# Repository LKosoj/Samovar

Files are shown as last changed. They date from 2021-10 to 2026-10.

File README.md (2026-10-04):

# Проект Самовар

[English version](README_EN.md)

## Описание
Автоматизированная система управления самогонным аппаратом, пивоварней и сыроварней на базе ESP32
(версия прошивки 7.00). Устройство измеряет температуры (пар, царга, куб, вода на выходе, ТСА) и
давление, управляет нагревом через регулятор мощности, реле, клапанами, насосом воды, шаговым
двигателем с перистальтическим насосом для отбора и сервоприводом для раздельного отбора по
ёмкостям. Процесс описывается программой из строк, которые выполняются последовательно, а логику
можно расширять скриптами на Lua. Управлять и наблюдать можно с локального дисплея, из встроенного
веб-интерфейса, из мобильных приложений для Android и iOS и со страницы на сайте samovar-tool.ru.
При выходе параметров за допустимые пределы устройство останавливает процесс и присылает тревогу.

## Режимы работы
- **Ректификация** — отбор голов, тела и хвостов по программе, детектор проскока примесей:
  анализирует тренд температуры с поправкой на давление, порог подбирает сам по шуму колонны,
  при росте температуры по желанию снижает скорость отбора, при критическом росте ставит отбор
  на паузу и сам возобновляет; на головах только наблюдает, а причину ожидания (грейс-период,
  стабилизация пара, набор истории) показывает в интерфейсе. Раздельный отбор по ёмкостям
  сервоприводом.
- **Дистилляция** — по температуре в кубе или по изменению спиртуозности в кубе или в паре, с
  прогнозом времени до конца строки и всего процесса.
- **БК (бражная колонна)** — управление водой охлаждения по уставке температуры пара
  (автоматически или вручную), подтверждение кипения по датчикам.
- **НБК (непрерывная бражная колонна)** — прогрев, настройка, оптимизация и работа; подача
  браги регулируется автоматически, найденные параметры можно принять как оптимальные.
- **Пивоварение** — засыпь солода, температурные паузы, кипячение, охлаждение, брожение, варочные
  порядки, управление мешалкой и насосом воды, ручная пауза.
- **Сувид** — термостат: держит заданную температуру по датчику куба в течение заданного
  времени выдержки (0 — без ограничения); уставка и время задаются в настройках.
- **Сыроварение** — нагрев, выдержки, охлаждение, контроль кислотности по датчику pH, мешалка,
  клапан слива; свои типы строк программы (нагрев, выдержка, охлаждение, перемешивание,
  дозирование, ожидание pH, флокуляция, ручное действие, слив, Lua).
- **Lua** — режим, в котором весь процесс ведёт пользовательский скрипт.

## Основные возможности
- Программа процесса для ректификации, дистилляции, БК, НБК, пива и сыра: набор строк,
  задаётся в веб-интерфейсе, выполняется последовательно. Подробнее в документации и на форуме.
- Плавное управление мощностью через внешние регуляторы (в том числе Kvic новой версии, РМВК,
  СЭМ) с автокоррекцией температуры кипения по атмосферному давлению.
- Точное управление отбором: скорость в литрах в час поддерживается автоматически.
- Плата расширения I2CStepper по шине I2C: мешалка и дозирующий насос на шаговых двигателях —
  прокачка, наполнение заданного объёма, калибровка «шагов на миллилитр», реле, внешний датчик.
  Управляется из веб-интерфейса, программы, Lua, мобильных приложений и сайта.
- Встроенный интерпретатор Lua для расширения логики: доступ к датчикам, нагреву, насосам,
  мешалке, реле.
- Безопасность: контроль температур, давления, воды, ошибок регулятора и датчиков; аварийная
  кнопка; при аварии процесс останавливается, а сообщение уходит на дисплей, в веб-интерфейс,
  в приложения и на сайт.
- Снимки состояния: после аварийной перезагрузки прошивка восстанавливает программу и, если
  процесс перезапущен в течение 30 минут, продолжает ту же сессию лога.
- Веб-интерфейс с графиками в реальном времени, схемой процесса и файловым менеджером; локальный
  LCD-дисплей с энкодером.
- Лог процесса и сообщения сохраняются в облаке (сервер samovar-tool.ru) и доступны на сайте и в
  приложениях; графики строятся по истории всей сессии.
- Мобильные приложения Android и iOS и страница управления на сайте (см. разделы ниже), push-
  уведомления о тревогах.
- Конфигуратор для Windows, macOS и Linux: сборка, прошивка по USB или Wi-Fi, редактор файлов
  устройства, отчёт о конфигурации.
- Поддержка ESP32 (DEVKIT, LILYGO) и ESP32-S3.

## Требования
### Аппаратные
- ESP32 (DEVKIT, LILYGO) или ESP32-S3
- Датчики температуры DS18B20 (5 шт)
- Датчик давления (MPX5010D, XGZP6897D или датчик 1-Wire), датчик атмосферного давления
  (BME680, BME280, BMP280 или BMP180)
- Регулятор мощности (Kvic, РМВК, СЭМ или аналог)
- LCD дисплей
- Энкодер с кнопкой
- Насос для подачи воды
- Шаговый двигатель
- Перистальтический насос
- Клапаны
- Сервопривод
- Блок питания
- По желанию: плата I2CStepper с мешалкой и дозирующим насосом, внешний АЦП ADS1115 и
  датчик pH PH-4502C для сыроварения, датчик протока воды, аварийная кнопка

Для режима «Сыр» используются общие контакты:

- `#define USE_ADS1115 0x48` автоматически переводит датчик pH на вход AIN0 ADS1115
  по адресу `0x48`. Отдельной настройки канала нет. `LUA_PIN` для pH не используется.
  Если ADS1115 не найден, запуск сыроварения и калибровка pH блокируются, но остальные
  режимы продолжают работать.
- Без `USE_ADS1115` входом PH-4502C служит `LUA_PIN`;
  оператор подключает к нему либо PH-4502C для сыра, либо MPX5010DP для других режимов,
  но не оба датчика одновременно.
- Реле №4 — клапан слива; оператор подключает к нему либо клапан для сыра,
  либо разгонный ТЭН для других режимов, но не оба устройства одновременно.

Это назначение действует только в режиме «Сыр». В остальных режимах Lua,
MPX5010DP и разгонный ТЭН работают как обычно.

Схема подключения
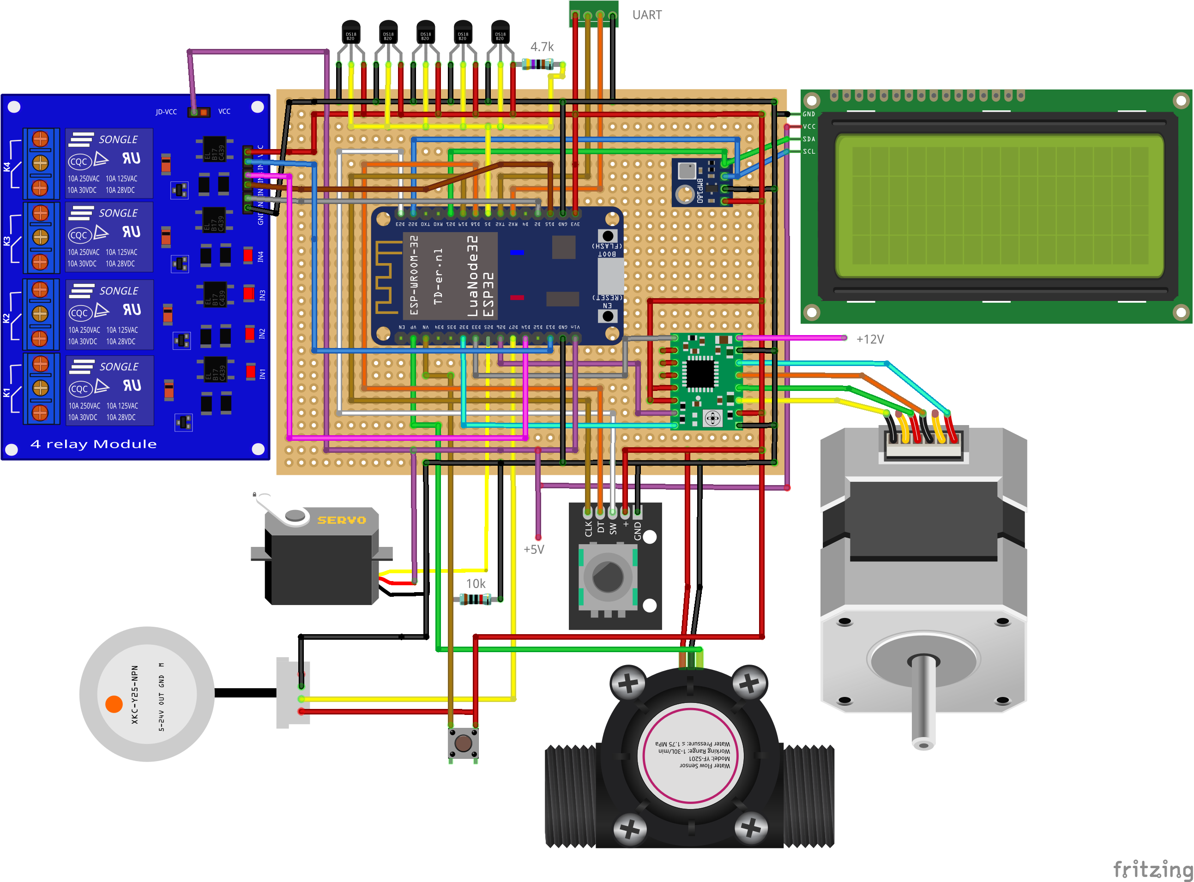
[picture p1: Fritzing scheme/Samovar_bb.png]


### Ограничения выводов ESP32
- GPIO34–39 — только входы, внутренних подтяжек нет: для аварийной кнопки (GPIO35 на DEVKIT), энкодера LILYGO (GPIO35/39/36) и датчика протока (GPIO36 на DEVKIT) обязателен внешний резистор 10 кОм к 3.3 В; без него — ложные срабатывания и уход в аварию сразу после включения.
- GPIO36/39 — ложные импульсы при работе АЦП и Wi-Fi: провода к датчику протока вести отдельно от силовых кабелей ТЭНа.
- GPIO15 и другие strapping-выводы аппаратно подтянуты при сбросе: реле на таком выводе (RELE_CHANNEL2, мешалка) кратковременно включается при каждой загрузке — использовать реле с активным низким уровнем либо перенести на обычный вывод; полярность задаётся полями rele1…rele4 в setup.htm.
- На ESP32-S3 кнопка меню (GPIO47) требует внешней подтяжки.
- Шина I2C (дисплей, плата расширения шагового двигателя, дозирующий насос): подтяжки 4.7–10 кОм; длина проводов и частота шины — причина срывов отрисовки, из-за которых в прошивке есть периодическая переинициализация дисплея.

### Программные
- Windows 10/11 x64: достаточно запустить `flash_windows.bat`. Он проверит или
  установит Python с Tkinter и PlatformIO, затем откроет конфигуратор Samovar.
- macOS и Linux: запустите `./flash_macos_linux.sh`. Он проверит или установит
  Python с Tkinter и PlatformIO, затем откроет тот же конфигуратор.
- Для ручной сборки на любой поддерживаемой системе нужен PlatformIO Core. Компилятор
  ESP32, платформу и зависимости проекта PlatformIO устанавливает автоматически по
  `platformio.ini`; отдельно собирать список библиотек не требуется.

## Установка

### Windows: конфигуратор

1. Скачайте или клонируйте репозиторий и запустите `flash_windows.bat` из его корня.
2. В открывшемся окне выберите плату и задайте параметры. Локальные настройки,
   включая исходные реквизиты Wi-Fi, сохраняются в `user_config_override.h`.
3. Нажмите «Прошить»: PlatformIO скомпилирует прошивку и загрузит её в ESP32.
4. При первой установке отдельно нажмите «Загрузить LittleFS», чтобы записать
   веб-интерфейс. Эта операция требует подтверждения, поскольку заменяет файлы на
   устройстве.
5. Последующие обновления можно ставить без кабеля. Нажмите «Обновить» рядом с
   полем «Порт или адрес»: кроме COM-портов в список попадают устройства Samovar,
   найденные в сети (mDNS, поиск занимает около трёх секунд), а также адрес,
   который устройство сообщило после кнопки «Получить IP» в мониторе порта. Адрес
   можно и ввести вручную (`192.168.1.37` или `samovar.local`). Выберите
   устройство в сети вместо COM-порта и нажмите те же «Прошить» или «Загрузить
   LittleFS» — PlatformIO сам передаст образ по Wi-Fi. Условия: прошивка на
   устройстве собрана с включённым «Разрешить обновление по Wi-Fi» (раздел
   «Сеть»), компьютер и Samovar в одной сети, брандмауэр разрешает `python.exe`
   входящие подключения — при передаче образа устройство само подключается к
   компьютеру. Полная очистка флеша, монитор порта и перезагрузка через esptool
   работают только по USB.

Кнопка «Редактор файлов» открывает файлы устройства прямо в конфигураторе:
с номерами строк, подсветкой Lua, JS, CSS, HTML и JSON, подсветкой парной
скобки и быстрой проверкой (баланс скобок и блоков `function … end`, незакрытые
строки и комментарии, корректность JSON). Ошибка показывается в строке состояния
с номером строки. Для подсказок при вводе и полной проверки синтаксиса кнопка
«Веб-редактор (/edit)» открывает тот же файл в редакторе Ace на устройстве; для сжатых файлов (.gz) кнопка недоступна, их редактируют здесь, конфигуратор распаковывает и запаковывает их сам.

Во всех полях и в журнале работает контекстное меню по правой кнопке мыши
(вырезать, копировать, вставить, выделить всё), а сочетания Ctrl+C, Ctrl+V,
Ctrl+X, Ctrl+A действуют и в русской раскладке.

`flash_windows.bat` только подготавливает инструменты и запускает
`tools/samovar_configurator.py`; компиляцию и загрузку выполняет PlatformIO.
Конфигуратор изменяет пользовательские параметры, но не заменяет компилятор:
прошивку всегда собирает PlatformIO отдельным шагом.

### Arduino IDE

Arduino IDE — отдельный поддерживаемый способ сборки и загрузки. Откройте
корневой `Samovar.ino`, выберите свою ESP32-плату и порт, затем соберите и загрузите
прошивку. Для первой установки отдельно загрузите LittleFS с подготовленным каталогом
`data/`; конфигуратор и PlatformIO для этого способа не обязательны.

### macOS и Linux: конфигуратор

1. Скачайте или клонируйте репозиторий. В macOS рекомендуется разместить папку проекта
   непосредственно в домашней папке, а не в защищённой папке `Downloads` («Загрузки»).
2. Откройте Terminal в папке проекта и выполните:

   ```sh
   chmod +x flash_macos_linux.sh
   ./flash_macos_linux.sh
   ```

3. В открывшемся окне настройте и прошейте устройство так же, как в Windows.

Если macOS выводит `getcwd: cannot access parent directories: Operation not permitted`
или не разрешает открыть `flash_macos_linux.sh`, оболочка не имеет доступа к текущей
папке и скрипт ещё не начал выполняться. Перенесите папку проекта через Finder из
`Downloads` в домашнюю папку и запустите его оттуда. Другой вариант: откройте
«Системные настройки» → «Конфиденциальность и безопасность» → «Файлы и папки»,
разрешите Terminal доступ к папке «Загрузки» и полностью перезапустите Terminal.

В macOS для автоматической установки Python и Tkinter требуется Homebrew. В Linux
поддерживаются `apt`, `dnf` и `pacman`; установка системных пакетов может запросить
пароль `sudo` (запуск команды с правами администратора).

### Ручная сборка PlatformIO

1. Установите PlatformIO Core и клонируйте репозиторий.
2. Задайте пользовательские параметры в `user_config_override.h`, взяв за основу
   `user_config_override.example.h`.
3. Соберите и загрузите нужное окружение: `pio run -e Samovar -t upload` для ESP32
   DEVKIT/LILYGO (для LILYGO добавьте в `user_config_override.h` строку `#define BOARD LILYGO`)
   или `pio run -e Samovar_s3 -t upload` для ESP32-S3.
4. Для первой установки веб-интерфейса выполните для того же окружения
   `pio run -e <окружение> -t uploadfs`.

## Языки

Язык прошивки и веб-интерфейса выбирается при прошивке; переключать его на работающем
устройстве нельзя. Доступны русский, английский (`en`), немецкий (`de`), французский
(`fr`), испанский (`es`) и китайский (`zh`). Каталог рецептов пива и сыра с сайта
открывается на языке устройства.

- **Конфигуратор.** В разделе «Основные» выберите «Язык прошивки и веб-интерфейса», затем
  «Прошить» и «Загрузить LittleFS»: конфигуратор сам соберёт образ веб-интерфейса на
  выбранном языке. Язык окна самого конфигуратора выбирается внизу окна и применяется
  после перезапуска.
- **Вручную.** Добавьте в `user_config_override.h` строку `#define SAMOVAR_LANG en`.
  Образ веб-интерфейса на английском собирается командой
  `python3 tools/build_web_assets.py --image en --out <каталог вне проекта>` (каталог не должен
  существовать или должен быть пустым); этот каталог
  загружается в LittleFS вместо `data/` (для PlatformIO — через переменную окружения
  `PLATFORMIO_DATA_DIR=<каталог>`).
- **Обновление веб-интерфейса по сети.** Устройство само скачивает с сервера файлы своего
  языка (`index.en.htm.gz` и т. п.) и сохраняет их под обычными именами. Ваши `.lua` и
  `program_*.txt` при этом не перезаписываются: после смены языка они остаются прежними,
  пока вы не удалите их или не загрузите LittleFS заново.

Русский текст остаётся в коде: строки прошивки записаны как `TR(КЛЮЧ, "русский текст")`,
перевод лежит в `lang_<код>.h`. Если для какой-то строки нет перевода, сборка падает с
ошибкой — подстановки русского текста вместо перевода нет. Веб-интерфейс переводится при
сборке `tools/build_web_assets.py` по словарю `i18n/web/<код>.json`, конфигуратор — по
`i18n/configurator/<код>.json`.

Чтобы добавить язык, положите в корень `lang_<код>.h` (по образцу `lang_en.h`), а также
`i18n/web/<код>.json` и `i18n/configurator/<код>.json`. Конфигуратор найдёт новый язык
сам. Полноту переводов проверяют `tools/smoke_i18n_firmware.py`, `tools/smoke_i18n_web.py`
и `tools/smoke_i18n_configurator.py`. После правки только `lang_<код>.h` выполните чистую
сборку (`pio run -e <окружение> -t clean`): PlatformIO не видит этот файл в зависимостях,
потому что имя подключаемого файла вычисляется макросом.

## Структура проекта
- `Samovar.ino` - основной файл проекта
- `Samovar.h` - основные определения
- `logic.h` - логика работы
- `WebServer.ino` - веб-сервер
- `Blynk.ino` - связь с сервером samovar-tool.ru (данные, команды, лог процесса)
- `SamovarMqtt.h` - необязательная отправка показаний в MQTT
- `I2CStepper.h`, `i2c_stepper_params.h` - плата расширения: мешалка и дозирующий насос по I2C
- `impurity_detector.h` - детектор проскока примесей
- `FS.ino` - файловая система, локальный лог и снимки состояния для восстановления после перезагрузки
- `crash_handler.h` - необязательный отчёт о сбое (`USE_CRASH_HANDLER`)
- `tools/samovar_configurator.py` - конфигуратор (запускается из `flash_windows.bat` и `flash_macos_linux.sh`)
- `beer.h` - режим пивоварения
- `cheese.h` - режим сыроварения
- `distiller.h` - режим дистилляции
- `BK.h` - режим бражной колонны
- `nbk.h` - режим непрерывной бражной колонны
- `lua.h` - интерпретатор Lua

### Веб-интерфейс

Интерфейс в «медной» палитре со светлой и тёмной темой (по настройке системы или
переключателем): схема процесса с живыми показаниями, текущая строка
программы, графики, страницы режимов, настройки, редактор программ и файлов.

Рабочие страницы загружаются как статические gzip-файлы и до первого опроса получают
начальные данные одним запросом `/ui-bootstrap`. Единственное исключение — `setup.htm`:
она остаётся несжатой шаблонной страницей.

### Редактор файлов устройства

Операции редактора `/edit`, меняющие файловую систему (`DELETE`, создание через
`PUT` и каждый чанк загрузки), пытаются без ожидания получить общий доступ к
файлам. Если журнал в этот момент занят, сервер отвечает `503 BUSY`; если доступ
свободен, операция разрешена и во время процесса. Просмотр и скачивание файлов
остаются доступны всегда.

### Связь с сервером, лог процесса и сессии

Связь устройства с сайтом и приложениями идёт через сервер samovar-tool.ru по протоколу Blynk
(TCP, порт 8080). По нему уходят живые показания и команды для приложений и сайта, а также лог
процесса, старт сессии и сообщения (виртуальные пины V34, V35 и V26): сервер сам записывает их в
базу, откуда их читают страница логов на сайте и графики в приложениях. Периоды фиксированы:
строка лога уходит на сервер раз в `LOG_PERIOD_S = 4` секунды, в локальный файл `data.csv`
пишется раз в `FILE_LOG_PERIOD_S = 16` секунд; настроек в веб-интерфейсе для этого нет. В простое
(нет активного процесса) показания всё равно уходят раз в 5 секунд, чтобы
приложения видели температуры и без запущенного процесса.

По желанию конфигуратор включает отдельную отправку сокращённой строки показаний в произвольный
MQTT-брокер. Сервер, порт, пользователь, пароль и топик хранятся только в локальном
`user_config_override.h`; веб-интерфейс устройства их не хранит. MQTT работает без TLS, отправляет
сообщения с QoS 1 и сохраняет последнее значение в брокере (`retain`). В процессе период равен
4 секундам, в простое — 5 секундам.

Если процесс прервался аварийной перезагрузкой и его же программу запускают заново в течение
30 минут, прошивка не открывает новую сессию, а продолжает прежнюю — сервер дописывает
существующую запись лога, а не создаёт новую.

## Мобильные приложения

Приложения для Android и iOS устроены одинаково и работают через сервер samovar-tool.ru:
при первом запуске регистрируют или используют существующий аккаунт (email и пароль),
в настройках задаётся токен устройства — тот же, что в прошивке, — или подключаются устройства,
добавленные на сайте.

Четыре основные вкладки и меню «Ещё»:
- **Основная** — состояние связи, схема процесса с живыми температурами, ключевые показания,
  текущая строка программы с прогрессом, кнопки нагрева, «Далее», паузы и сброса процесса,
  блок режима (спиртуозность, детектор примесей, прогнозы, подача браги, pH и т. д.).
- **Программа** — все строки программы с расшифровкой полей, выполняемая строка подсвечена.
- **Управление** — напряжение, скорость отбора, фиксация температуры тела, мешалка и насос
  I2CStepper (настройки, запуск, калибровка, реле), выполнение строк Lua с ответом устройства,
  системная информация, сообщения за сеанс.
- **Графики** — история текущей сессии из базы сервера плюс живые точки, группы серий и
  интервалы от 1 минуты до всей сессии.
- **Ещё** — разделы «Сыровар» и «Пивовар» (журналы, рецепты, склад, калькуляторы), «Винокур»
  (журналы, калькуляторы) и «Настройки» (токен или устройства сайта, аккаунт, тема оформления).

Данные обновляются раз в 3 секунды, пока приложение на экране. Тревоги приходят push-уведомлением
с громким сигналом и показываются поверх экрана блокировки. На планшете экраны двухколоночные.

## Управление через сайт samovar-tool.ru

На сайте есть страница https://www.samovar-tool.ru/control/ — экраны Основная, Программа,
Управление, Графики и Сообщения, как в мобильных приложениях, без установки чего-либо на телефон
или компьютер. Условия:

- нужно войти на сайт;
- к аккаунту должно быть добавлено устройство (токен тот же, что в прошивке и в приложениях) —
  на странице «Пользователь → Устройства». Если устройств несколько, нужное выбирается на странице
  управления. Без устройства страница сообщает, что его сначала нужно добавить.

Сайт обращается к серверу от имени пользователя сам, токен в браузер не передаётся.
Команды отправляются только когда устройство в сети, при устаревших данных кнопки блокируются.
Страница логов https://www.samovar-tool.ru/logi/ (список сессий, графики, сообщения, выгрузка
CSV) дополняет страницу управления.

## Документация
Полная документация доступна на сайте: https://www.samovar-tool.ru/

[Техническая документация](/doc/tutorial.md)

## Поддержка
Проект некоммерческий. Обсуждение и поддержка на форуме:
https://forum.homedistiller.ru/index.php?topic=367128.0

## Демонстрация
Примеры работы системы: https://www.samovar-tool.ru/2021/03/21/o-rabote-samovara/

## Сравнение с другими проектами

### Ректификация/дистилляция
Давайте сравним функционал проекта "Самовар" с коммерческими решениями для ректификации и дистилляции, разделив их на три категории:

1.  **Базовые цифровые контроллеры** (например, популярные PID-регуляторы в коробке, контроллеры от Still Spirits и т.п.).
2.  **Продвинутые хоббийные контроллеры** (например, системы от HomeDistiller, кастомные сборки от известных производителей оборудования).
3.  **Промышленные/лабораторные ПЛК-системы** (Programmable Logic Controller — программируемые логические контроллеры).

---

### Сравнительный анализ функционала для дистилляции/ректификации

| Функциональный блок | Проект "Самовар" (DIY) | Базовый контроллер | Продвинутый хобби-контроллер | Промышленный ПЛК |
| :--- | :--- | :--- | :--- | :--- |
| **1. Основная логика управления** | **Динамическое управление процессом.** Логика зависит от стадии, температуры, давления, времени и **событий**. | **Статическое поддержание параметра.** Обычно это термостат: держит заданную температуру или мощность. | **Пошаговое программирование.** Выполнение рецепта вида: "греть до 80°С -> держать 20 мин -> греть до 90°С". | **Полностью программируемая логика.** Реализуется любая, даже самая сложная взаимосвязь между параметрами. |
| **2. Управление мощностью** | **Плавное, точное.** ПИД-регулирование мощности через внешние регуляторы (симисторы, SSR). | **Дискретное (Вкл/Выкл).** Простое реле, приводящее к инерционным скачкам температуры. | **Плавное.** Обычно ПИД-управление через ФИМ (фазо-импульсная модуляция) для SSR. | **Плавное, прецизионное.** Управление с обратной связью по мощности. |
| **3. Управление отбором продукта** | **Ключевая функция.** **Высокоточное управление шаговым двигателем насоса** или сервоприводом клапана. Скорость отбора задается в л/ч и автоматически поддерживается. | **Отсутствует.** Управляется вручную оператором. | **Обычно отсутствует или опционально.** Может управлять простым клапаном (открыт/закрыт), но редко — скоростью отбора. | **Полный контроль.** Управление любыми типами клапанов и насосов с контролем потока. |
| **4. Адаптивность к процессу** | **Очень высокая.** **Автокоррекция температуры кипения по давлению.** **Автоматическое снижение скорости отбора** при "подходе хвостов". **Полная кастомизация логики через Lua.** | **Нулевая.** Не реагирует ни на что, кроме отклонения от заданной температуры. | **Низкая.** Может переключить шаг рецепта по событию (например, по достижению температуры), но не может динамически изменять параметры текущего шага. | **Абсолютная.** Логика пишется под конкретную установку и процесс. |
| **5. Интерфейс и мониторинг** | **Современный.** Веб-интерфейс с графиками в реальном времени, удаленный доступ, локальный LCD. | **Примитивный.** Цифровой индикатор и несколько кнопок. | **Функциональный, но утилитарный.** Часто это текстовый LCD, опционально — вывод данных на ПК через RS-485/USB. | **Промышленный.** SCADA-системы с полной визуализацией процесса, архивацией, отчетами. |
| **6. Безопасность** | **Многоуровневая, настраиваемая.** Контроль температуры, давления, воды, ошибок питания. Логика аварии задается пользователем. | **Базовая.** Обычно только защита от перегрева. | **Хорошая.** Контроль нескольких датчиков, сторожевые таймеры. | **Максимальная.** Дублирование систем, сертифицированные компоненты, аппаратные защиты. |
| **7. Интеграции (IoT)** | **Встроенные.** Облачный лог, мобильные приложения Android/iOS, управление через сайт samovar-tool.ru. | **Отсутствуют.** | **Редко.** Обычно это проприетарные протоколы или ModBus для связи с ПК. | **Стандарт.** OPC-UA, ModBus, Profinet и др. промышленные протоколы. |
| **8. Примерная стоимость** | **Низкая** (~$50-100 за электронику). | **Низкая** (~$50-150). | **Средняя/Высокая** (~$300-800). | **Очень высокая** (тысячи $). |

---

### Позиционирование "Самовара" относительно других проектов для дистилляции

1.  **"Самовар" на голову превосходит базовые контроллеры.** Он не просто заменяет их, а предлагает совершенно иной уровень автоматизации. Там, где базовый контроллер — это "умная розетка", "Самовар" — это "мозг" установки.

2.  **"Самовар" является прямым и очень сильным конкурентом продвинутым хобби-контроллерам.** Он не только не уступает им в основных функциях (ПИД-регулирование мощности, пошаговые программы), но и **превосходит их в двух критически важных для ректификации областях:**
    *   **Интегрированное управление отбором:** У коммерческих систем управление отбором — это, как правило, отдельное, дорогое устройство. "Самовар" делает это своей основной функцией.
    *   **Гибкость логики:** Ни один коммерческий хобби-контроллер не предлагает программирование логики на уровне Lua. Эта возможность переносит "Самовар" в полупрофессиональную лигу, позволяя реализовать алгоритмы, доступные ранее только на промышленных ПЛК.

3.  **"Самовар" заимствует концепции у промышленных ПЛК-систем.** Идея полностью программируемой логики, реагирующей на множество асинхронных событий, — это основа ПЛК. "Самовар" демократизирует этот подход, делая его доступным для хоббиста на дешевой аппаратной базе. Разумеется, он уступает в надежности, помехозащищенности и не имеет промышленных сертификатов, но с точки зрения **функциональной логики** — он стремится именно в эту высшую лигу.

**Итоговый вывод:**

Проект "Самовар" — это не просто DIY-поделка. В контексте оборудования для дистилляции/ректификации он представляет собой **систему, которая по своему функционалу оставляет далеко позади остальные DIY решения и напрямую конкурирует с дорогими продвинутыми контроллерами, превосходя их в гибкости и возможностях кастомизации.**

Его главный компромисс — это не функционал, а **"удобство против гибкости"**. Покупая коммерческий прибор, вы получаете гарантию, поддержку и готовое к работе устройство. Выбирая "Самовар", вы получаете практически безграничные возможности для автоматизации в обмен на необходимость самостоятельно собирать, настраивать и обслуживать систему.

### Сравнительный анализ функционала для режима пивоварения

Ниже приведен сравнительный анализ функционала проекта "Самовар" с другими популярными open-source/DIY проектами в области автоматизации пивоварения.

Для сравнения возьмем несколько известных проектов, представляющих разные подходы:
1.  **BrewPi / BrewPiLess:** Исторически один из самых известных проектов для **контроля ферментации** пива.
2.  **CraftBeerPi (v3/v4):** Очень популярный и модульный контроллер для **пивоварения** (затирание, кипячение), работающий на Raspberry Pi.
3.  **ArdBir / ESPurno:** Более простые контроллеры на Arduino/ESP, ориентированные в основном на процесс пивоварения.

---

### Сравнительный анализ по ключевым параметрам

| Функциональный блок | Проект "Самовар" | BrewPi / BrewPiLess | CraftBeerPi 4 | Типичные DIY-проекты (ArdBir и др.) |
| :--- | :--- | :--- | :--- | :--- |
| **1. Целевое назначение** | **Универсальный.** Дистилляция, ректификация, пивоварение, НБК. | **Специализированный.** В основном, точный контроль температуры ферментации. | **Специализированный.** Полный цикл пивоварения (затирание, кипячение). | **Специализированный.** Обычно только пивоварение (затирание). |
| **2. Гибкость автоматизации** | **Очень высокая.** Пошаговые программы + **Lua-скрипты** для любой кастомной логики. | **Средняя.** Профили температуры (график "температура-время"). | **Высокая.** Пошаговые рецепты, гибкая система плагинов для расширения. | **Низкая.** Жестко заданная логика, максимум — настройка температурных пауз. |
| **3. Управление оборудованием** | **Точное и комплексное.** Управление шаговым двигателем (точный отбор), сервоприводом (смена емкостей), плавная регулировка мощности. | **Точное.** ПИД-управление нагревом и охлаждением для поддержания температуры. | **Модульное.** Управление клапанами, насосами, мешалкой через реле. PWM для мощности. | **Базовое.** В основном, релейное управление (включил/выключил). |
| **4. Интерфейс и мониторинг** | **Комплексный.** Веб-интерфейс с графиками, файловым менеджером + локальный LCD-дисплей с энкодером. | **Минималистичный.** Веб-интерфейс для настройки профиля и просмотра графика. | **Продвинутый.** Современный веб-интерфейс, полностью настраиваемая панель приборов. | **Базовый.** Обычно только LCD-дисплей, редко — простой веб-интерфейс. |
| **5. Интеграции и IoT** | **Встроенные.** Облачный лог, мобильные приложения Android/iOS, управление через сайт samovar-tool.ru. | **Ограниченные.** Интеграция с iSpindel, в некоторых форках есть MQTT. | **Широкие (через плагины).** MQTT, iSpindel, оповещения и многое другое. | **Практически отсутствуют.** |
| **6. Аппаратная платформа** | **ESP32.** Низкая стоимость, высокая производительность для real-time задач. | **ESP8266/ESP32.** | **Raspberry Pi.** Полноценный компьютер, выше стоимость и энергопотребление. | **Arduino/ESP8266.** |

---

### Заключение и позиционирование проекта "Самовар"

Проект "Самовар" занимает **уникальную нишу на стыке профессиональной гибкости и DIY-доступности**, сильно выделяясь на фоне аналогов.

**1. "Самовар" — это швейцарский нож, в то время как конкуренты — это специализированные инструменты.**
Большинство проектов (CraftBeerPi, BrewPi) созданы для решения одной задачи — пивоварения. Они делают это хорошо, но их логика и функционал не подходят для ректификации. "Самовар" изначально спроектирован как универсальная платформа, способная управлять кардинально разными процессами. Это его главное и самое сильное отличие.

**2. Уровень автоматизации "Самовара" на порядок выше.**
В то время как другие проекты предлагают параметризацию (задать температуру, время) или пошаговые рецепты, "Самовар" идет дальше, дополнительно предлагая **полноценное программирование логики через Lua**. Это позволяет опытным пользователям реализовывать сложнейшие алгоритмы, которые невозможно реализовать в других системах без модификации их исходного кода.

**3. "Все в одном" на доступной платформе.**  
"Самовар" предоставляет функционал (веб-сервер, графики, сложная логика, множество интеграций), который у конкурентов часто требует более мощной и дорогой платформы, как Raspberry Pi (в случае с CraftBeerPi). При этом он сохраняет преимущество микроконтроллеров (ESP32) — надежность и работу в режиме реального времени.

**4. "Самовар" — это не просто контроллер.**  
"Самовар" — это не просто контроллер. Это универсальная платформа, которая может управлять множеством процессов. Это позволяет опытным пользователям реализовывать сложнейшие алгоритмы, которые невозможно реализовать в других системах без модификации их исходного кода.

**Вывод:**

Проект "Самовар" не является "просто еще одним контроллером". Это **высокоуровневый процессинговый контроллер**, ориентированный на энтузиастов, которые хотят получить максимальный контроль над процессами пивоварения, ректификации, дистилляции, бражной колонны и т.д.

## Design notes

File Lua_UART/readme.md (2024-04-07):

Монитор COM порта.
Скетч принимает по UART строку в юникоде, дробит её на 8 подстрок (разделитель запятая ",", максимум 20 символов) и выводит их на дисплей. В конце тоже должна быть запятая.
Можно LUA скриптом командой print выводить себе на отдельный дисплей что угодно. Но только одной командой print.

Исходное сообщение тут: https://forum.homedistiller.ru/msg.php?id=14049195

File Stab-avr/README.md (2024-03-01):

Версия стабилизатора мощности, которым может управлять Samovar. Прост в сборке и настройке.

Оригинальная версия: https://github.com/JohnJohnov/Stab-avr

Основное отличие от оригинальной версии - снижены задержки при старте. Оригинальная загружается больше 5 секунд, что при управлении через Samovar очень не удобно.

***
Схема устройства

-----------
Небольшой FAQ:

Если с Nano происходит что-то не понятное, скорее всего проблема связана с питанием. 
Необходимо добавить конденсатор микрофарад на 2000 или больше непосредственно на ноги ардуино +5 и Gnd.
Между RST и Gnd микрофарад на 50. Скорей всего поможет.

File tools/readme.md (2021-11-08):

Загрузка страниц для web-сервера. Необходимо сделать до первого запуска. Для этого необходимо в каталоге с Arduino создать катлог tools, и распаковать в него содержимое архива ESP32FS-1.0.zip
Подробнее - https://randomnerdtutorials.com/install-esp32-filesystem-uploader-arduino-ide/

Так же для загрузки можно использовать специальный скетч и приложение
https://www.pvsm.ru/arduino/342664
Утилита для WIN/MAC и скетч в архиве

Blynk.png - ссылка на приложение в Blynk. Для того, чтобы воспользоваться, необходимо установить на Android или iPhone приложение Blynk, после чего отсканировать QR-код с картинки. Blynk загрузит приложение Самовар. В приложении необходимо сгенерировать код, который потом вставить в настройках Самовара в браузере. Полная версия приложения требует 8000 единиц энергии.

Blynk_Light.png - облегченная версия приложения, для ее установки нет необходимости докупать энергию. Функционал по сравнению с полной версией будет обрезан - температура пара и царги, включить/выключить.

Расчет АС-3.xlsx - файл Excel для генерации программы. Задаются параметры отобора - объем СС, крепость, количество голов, количество хвостов, на выходе получается программа отбора для Самовара.

chartlocal.htm - страничка для анализа логов. Для работы необходимо поднять локальный web-сервер. Самый простой вариант - установить PHP или Python, у них есть встроенные легкие web-сервера, подробнее описано на страничке

Samovar_default_settings.txt - файл с начальными настройками Самовара. Описание доступно тут https://www.samovar-tool.ru/2021/03/24/nastrojka-parametrov-samovara/

program_shugar.txt, program_grain.txt, program_fruit.txt - файлы с шаблонами расчета программ отбора для сахара, зерна и фруктов. Описание доступно тут https://www.samovar-tool.ru/2021/03/27/kak-sostavit-programmu-otbora-dlja-samovara/

Pump3D.zip - 3D-модель для печати головы насоса. Описание доступно тут https://alcodistillers.ru/forum/viewtopic.php?pid=185555#p185555

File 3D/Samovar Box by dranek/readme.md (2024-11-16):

https://forum.homedistiller.ru/msg.php?id=14078558

Печатал ABS, потому что считаю его самым проблемным из-за больших термодеформаций после остывания. Лучше всего будет скорей всего из PLA.
Корпус можно распечатать в минимальном виде - Сама коробка (Body.stl) плюс верхняя крышка (Top.stl). Тогда при необходимости блока реле его придется расположить в другом месте, например рядом с регулятором мощности, а с Самоваром соединить семижильным кабелем.
Крышки привинчиваю винтами м3 10мм с головкой в потай, для этого рассверливаю намеченные отверстия до 3 мм. Можно использовать и шурупы, на ваш выбор. Цоколь с корпусом соединяется подобным образом, но у меня нашлось 4 винта потоньше.
В случае исполъзования цоколя нужно в дне корпуса высверлить по намеченным отверстиям и выломать 6 прорезей по краям для вентиляции цоколя и прокладки проводов.
Есть вариант верхней крышки без дисплея, энкодера и кнопки (Top_no LCD.STL).
Вентилятор заложен 50*50*10 мм 12В. Плотно одевается на штырьки верхней крышки с натягом, так что можно дополнительно не привинчивать. Я его подключаю вместо насоса воды. В новом варианте платы добавил возможность запайки гнезд разъёмов для вентилятора на 12 и 5В.
Можно распечатать дополнительно цокольный этаж (Body2.stl) и нижнюю крышку (Bottom.stl), тогда появится место для блока реле, дополнительных разъёмов и др., например блока питания, расширителя портов, драйвера ШД для NEMA23 насоса НБК. На нижней крышке предусмотрено крепление для скобы на колонну. Скоба пластиковая польская, предназначена для труб канализации 50 мм, купил в строймаркете несколько и использую.
Разъёмы я использую GX12, для их установки нужно выбрать удобное место по намеченным мини отверстиям в боковых стенках корпуса и цоколя, убедиться, что разъем не упрётся в другие элементы, рассверлить на нужный диаметр.
Можно использовать другие свои разъёмы по тому же принципу. В случае использования цоколя разъёмы и выключатель рядом с штекером питания предпочтительнее устанавливать в него.
Для разъёмов запаянных на плату тоже самое, выбираем нужные миниотверстия, высверливаем, уголки отламываем, подравниваем надфилем, скальпелем и т.п.
Со стороны модуля c ESP32 предусмотрена возможность вырезания большого прямоугольного выреза. Оно мне нужно для возможности перепрошивки / отладки через USB не изымая микроконтроллер из корпуса. Отключаем основное питание полностью (достаем штекер из разъёма обязательно) подключаем к USB PC, шьем, смотрим COM порт. Через этот же вырез есть возможность снять пинцетом джампер (который можно ведь и под углом 90 гр. запаять). Джампер нужно снимать, если есть необходимость отладки с подключенным основным питанием Самовара. При этом в качестве PC необходимо использовать ноутбук с питанием от батареи либо использовать гальваническую развязку USB. Соответственно нужно будет еще распечатать заглушку для этого выреза (stub.STL).
Можно распечатать логотип с названием (Logo.STL) и приклеить где удобно. Печатать двумя цветами соответственно.

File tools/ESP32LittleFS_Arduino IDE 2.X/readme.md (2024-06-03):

Загрузчик LittleFS, совместимый с Arduino IDE 2.2.1 или выше

Установка:

Скопируйте файл VSIX на ~/.arduinoIDE/plugins/Mac и Linux или C:\Users\<username>\.arduinoIDE\plugins\в Windows (возможно, вам придется создать этот каталог). Перезапустите IDE.

Применение:

Чтобы открыть палитру команд в Arduino IDE,
В Windows нажмите [Ctrl]+ [Shift]+ [P],
В macOS нажмите [⌘]+[Shift]+[P]

Затем введите «Upload LittleFS to Pico/ESP8266/ESP32».

Данные будут загружены.

Источник:
https://github.com/earlephilhower/arduino-littlefs-upload

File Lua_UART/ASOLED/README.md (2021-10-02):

# ASOLED
Библиотека для i2c 128х64 OLED дисплея на базе SSD1306.
Ветка на форуме, где была выложена автором: http://arduino.ru/forum/programmirovanie/kirillitsa-na-displee-ili-chto-ya-delayu-ne-tak
Новая версия от автора: http://arduino.ru/forum/proekty/asoled-kompaktnaya-biblioteka-dlya-oled-displeya-128kh64-s-kirillitsei-utf-8
Datasheet на контроллер дисплея: https://cdn-shop.adafruit.com/datasheets/SSD1306.pdf

Создание библиотеки преследовало две цели:
1. Добиться, чтобы без всекого шаманства что мы видим на экране в Arduino IDE, то же было на дисплее.
2. Уменьшить расход оперативной памяти при использовании библиотеки.

Вторая цель достигнута за счет отказа от экранного буфера в оперативной памяти. И, соответственно, вынужденного отказа от пиксельной графики: библиотека может выводить только текст или битмап. При этом высота как текста, так и битмапа должна нацело делиться на 8, а Y-координата также должна быть кратна 8. Это - плата за экономию памяти. Исправить это нельзя, если указанные ограничения критичны, пользуйтесь другой библиотекой - с экранным буфером объемом 1 киб.

В последней версии (0.4) добавлено
1. переключение ориентации (нормальный и кверху тормашками)
2. поддержка строк из PROGMEM
3. установка скорости для Arduino Due
4. добавлена поддержка 1.3" OLED SH1106
 
Комментарии:
1. В Arduino почему-то считается, что экран должен располагаться так, чтобы пины были сверху дисплея. А производитель дисплея, наоборот, сделал режимом по умолчанию тот, где пины снизу. И последнее логично: при раз0мещении экрана на лицевой панели совместно с другими органами управления более благоприятное расположение дисплея именно такое. Поэтому кроме "прямного" режима сделан "кверху тормашками" - какждый сам выбирает, как сориентировать дисплей в своей конструкции.
2. Собственно, теперь можно располагать строковые константы в PROGMEM: F("Моя новая строка")
3. Библиотека для увеличения скорости работы переключает шину I2C со стандлартных 100 кГц на 400 кГц. Теперь и для Arduino Due - тоже. Скажу по секрету: я добился устойчивой работы этой библиотеки на Arduino Due с имеющимся у меня дисплеем на 2 МГц.
4. Для подключения такого дисплея нужно раскомментировать одну строку в ASOLED.h. Если этого не сделать, то, в принципе, работать все равно будет - но со сдвижкой на 2 пиксела вправо.

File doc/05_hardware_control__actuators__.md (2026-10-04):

# Глава 5: Аппаратное управление (Исполнительные механизмы)

Добро пожаловать обратно в руководство по Самовару! В предыдущей главе, [Глава 4: Получение данных с датчиков](04_sensor_data_acquisition_.md), мы рассмотрели, как Самовар использует свои датчики, чтобы "видеть" и собирать данные из физического мира – такие параметры, как температура, давление и скорость потока. Эти данные в реальном времени предоставляют Самовару важную информацию о том, что происходит в процессе приготовления или дистилляции.

Но просто *знать* температуру или объем недостаточно. Самовар – это не только устройство для мониторинга; это система управления. Ему необходимо *действовать*, физически взаимодействовать с оборудованием для дистилляции или варки. Ему нужны "руки" и "голос", чтобы что-то включать или выключать, регулировать мощность, перемещать жидкости или издавать звуки.

Именно здесь вступает в игру **Аппаратное управление (Исполнительные механизмы)**. Исполнительные механизмы — это компоненты, которые позволяют Самовару физически управлять установкой. Это активные части системы, которые принимают решения, выработанные управляющей логикой (на основе шагов программы, состояния системы и данных с датчиков), и преобразуют их в физические действия.

## Почему исполнительные механизмы важны: пример использования

Давайте вернемся к нашему примеру ректификации. Представим, что Самовар с помощью температурного датчика (как обсуждалось в Главе 4) обнаружил, что температура пара на верху колонны достигла целевого значения для сбора "Тела" (основной части дистиллята).

Просто знать эту температуру бесполезно, если Самовар не может *действовать* на основании этой информации. Ему необходимо:

1.  Открыть клапан или включить насос для начала сбора жидкого продукта.
2.  При необходимости отрегулировать мощность, подаваемую на нагревательный элемент, чтобы поддерживать стабильные условия.
3.  Направить собранную жидкость в нужную емкость с помощью распределительного механизма.
4.  Возможно, даже включить зуммер, чтобы оповестить вас о переходе к следующему шагу программы.

Все эти действия выполняются **исполнительными механизмами**.

## Руки и голос Самовара: типы исполнительных механизмов

Аппаратная часть Самовара включает различные исполнительные механизмы для выполнения разных задач:

*   **Нагревательный элемент (управляется регулятором мощности/напряжения или реле):** Это основной источник нагрева для емкости. Его можно просто включать/выключать с помощью реле или, в более продвинутых установках, точно регулировать мощность или напряжение для поддержания температуры или контроля скорости пара.
*   **Клапан/насос охлаждающей воды (управляется реле или ШИМ):** Управляет подачей охлаждающей воды в конденсатор. Это может быть простой клапан (вкл./выкл. через реле) или насос, скорость которого регулируется с помощью ШИМ (широтно-импульсной модуляции) на основе обратной связи с температурного датчика.
*   **Перистальтический насос/шаговый двигатель (управляется драйвером шагового двигателя):** Используется для точного контроля скорости потока и общего объема собранной жидкости во время дистилляции. Шаговый двигатель обеспечивает точные, повторяемые движения — идеально для дозирования определенных объемов.
*   **Мотор/насос мешалки (управляется реле или I2C):** В режимах варки (например, затирание) перемешивает содержимое емкости или рециркулирует жидкость. Обычно это простая функция вкл./выкл. через реле, либо управление через устройство на шине I2C.
*   **Механизм распределения жидкости (управляется сервоприводом или реле):** Направляет собранную жидкость (головы, тело, хвосты) в разные приемные емкости. Это может быть сервопривод, позиционирующий носик, или набор клапанов/реле для выбора пути.
*   **Зуммер (управляется цифровым выходом):** Простой звуковой сигнализатор для оповещения пользователя о важных событиях (смена шага программы, ошибки и др.).

Каждый из этих исполнительных механизмов подключен к микроконтроллеру Самовара (ESP32) через специальные управляющие пины или коммуникационные шины (например, I2C или UART для регуляторов мощности). Программное обеспечение отправляет команды на эти интерфейсы, чтобы исполнительные механизмы выполняли свои функции.

## Как работает управление исполнительными механизмами

Управление исполнительным механизмом заключается в указании ему, *что* делать (например, включить, задать скорость, переместить в позицию) и зачастую *насколько* или *как быстро*. Этот процесс принятия решений определяется основной логикой Самовара, объединяющей информацию из шагов программы ([Глава 2](02_process_program_execution_.md)), текущего состояния системы ([Глава 3](03_system_state___mode_management_.md)) и данных датчиков в реальном времени ([Глава 4](04_sensor_data_acquisition_.md)).

Например:
*   **Шаг программы:** Шаг может требовать "Собрать 500 мл голов со скоростью 0,2 л/ч". Логика выполнения программы считывает это, дает команду контроллеру шагового двигателя двигаться медленно рассчитанное количество шагов для 500 мл и устанавливает исполнительный механизм выбора емкости в позицию 1.
*   **Состояние системы:** Если состояние системы меняется на "Нагрев", логика управления включает основной нагревательный элемент. Если состояние переходит в "Авария", нагрев выключается и включается зуммер.
*   **Данные датчиков:** Если датчик температуры охлаждающей воды сообщает, что вода стала слишком горячей, исполнительному механизму клапана/насоса может быть дана команда открыть сильнее или увеличить скорость.

Программное обеспечение Самовара предоставляет набор функций, которые абстрагируют низкоуровневые детали общения с конкретным исполнительным механизмом. Эти функции — "командный интерфейс" для исполнительных механизмов.

## Использование управления исполнительными механизмами: пример шагового двигателя и нагревателя

Рассмотрим управление двумя наиболее важными исполнительными механизмами во время обычной программы дистилляции: основным нагревателем и насосом сбора жидкости (шаговым двигателем).

В соответствии с шагами программы, определенными в [Глава 2](02_process_program_execution_.md), Самовар должен:

1.  Включить основной нагреватель (обычно сначала на полную мощность для разогрева).
2.  Когда условия станут подходящими (например, начнется кипение, стабилизируется колонна, определяется датчиками и логикой состояния), при необходимости уменьшить мощность нагревателя для стабильной работы.
3.  Включить шаговый двигатель/насос на определенной скорости и в нужном направлении.
4.  Отслеживать объем собранной жидкости по количеству шагов шагового двигателя.
5.  Остановить шаговый двигатель при достижении целевого объема для текущего шага программы.

Эти действия инициируются логикой выполнения программы, вызывающей специальные функции для управления этими исполнительными механизмами.

## Внутренняя реализация: поток управления

Когда Самовар решает выполнить действие с исполнительным механизмом, команда проходит через систему следующим образом:

```mermaid
sequenceDiagram
    Program Execution->>Control Logic: Command (e.g., "Start Step 1")
    Control Logic->>Actuator Control Function: Call stepper_safe_set_target(steps), startService()
    Actuator Control Function->>Hardware Driver: GyverStepper2 + hardware timer (or I2CStepper board via I2C)
    Hardware Driver->>Physical Stepper Motor: Send step/direction pulses
    Physical Stepper Motor-->>Program Execution: (Implicitly, by changing state monitored by sensors/counters)

    Program Execution->>Control Logic: Command (e.g., "Heating State")
    Control Logic->>Actuator Control Function: Call set_current_power(voltage)
    Actuator Control Function->>Power Regulator: Power regulator task sends the command via UART2
    Power Regulator->>Physical Heating Element: Adjust power/voltage
    Physical Heating Element-->>Sensors: Changes temperature (monitored by sensors)
```

В этом упрощенном потоке:
1.  Логика **Выполнения программы** (или общая логика Самовара в зависимости от режима/состояния) определяет, что требуется действие исполнительного механизма.
2.  Она вызывает функцию в слое **Логики управления** (например, `run_program` или `beer_stage_tick`).
3.  Эта функция логики управления вызывает конкретную **Функцию управления исполнительным механизмом** (например, `stepper_safe_set_target` и `startService` или `set_current_power`).
4.  Функция управления исполнительным механизмом содержит код, который напрямую взаимодействует с **Драйвером оборудования** (это может быть библиотека или собственный код для I2C, Serial или GPIO).
5.  Драйвер оборудования отправляет необходимые сигналы или команды на **Физический исполнительный механизм**, заставляя его выполнять нужное действие.

Такой многоуровневый подход делает основную логику программы чистой; ей не нужно знать низкоуровневые детали *как* обращаться к каждому устройству, достаточно знать *какую* функцию вызвать.

## Погружение в код

Рассмотрим упрощенные фрагменты кода, показывающие, как Самовар управляет своими исполнительными механизмами.

### Управление шаговым двигателем (перистальтический насос)

Шаговый двигатель играет ключевую роль для точного сбора жидкости. Основной насос отбора подключён к ESP32 напрямую (пины `STEPPER_STEP`, `STEPPER_DIR`, `STEPPER_EN` из `Samovar_pin.h`) и управляется объектом `stepper` библиотеки `GyverStepper2` (`GStepper2<STEPPER2WIRE>`, объявлен в `Samovar.h`). Импульсы шагов генерирует аппаратный таймер: `startService()` запускает его, `stopService()` останавливает, а в его прерывании `StepperTicker()` вызывается `stepper.tickManual()`. Задачи обращаются к `stepper` только через обёртки `stepper_safe_*` из `runtime_helpers.h`, которые защищают объект от одновременного доступа из прерывания.

```c++
// Упрощённый фрагмент из logic.h (run_program): запуск отбора строки программы
CurrrentStepperSpeed = get_speed_from_rate(program[num].Speed);      // л/ч -> шагов в секунду
TargetStepps = (uint32_t)program[num].Volume * SamSetup.StepperStepMl; // мл -> шаги (калибровка насоса)
stepper_safe_set_max_speed(CurrrentStepperSpeed);
stepper_safe_set_current(0);           // Начать отсчёт шагов с 0 для этой строки
stepper_safe_set_target(TargetStepps); // Задать количество шагов
startService();                        // Запустить таймер, генерирующий импульсы шагов

// Упрощённый фрагмент из Samovar.ino
void startService(void) {
  // Период таймера берётся из библиотеки (Arduino core 3.x; для core 2.x - timerAlarmWrite/timerAlarmEnable)
  timerAlarm(timer, stepper.getPeriod(), true, 0);
}

void IRAM_ATTR StepperTicker(void) { // Прерывание таймера
  portENTER_CRITICAL_ISR(&timerMux);
  StepperMoving = stepper.tickManual(); // Сделать шаг, если пора
  portEXIT_CRITICAL_ISR(&timerMux);
}
```

Скорость (`CurrrentStepperSpeed`) и общее количество шагов (`TargetStepps`) рассчитываются из строки программы. Прогресс отбора система отслеживает через `stepper_safe_get_current()`, а `set_pump_speed()` (`logic.h`) меняет скорость на ходу.

Второй насос и мешалка могут работать на плате I2CStepper — отдельном микроконтроллере (Arduino Nano), который управляет двигателем и получает команды по I2C. Для неё в `I2CStepper.h` есть функции `set_stepper_target()` (насос: заданное число шагов), `set_stepper_by_time()` (мешалка: обороты в минуту на заданное время) и `set_mixer_pump_target()` (реле 1 платы).

```c++
// Фрагмент из I2CStepper.h
inline bool set_stepper_target(uint32_t speedStepsPerSecond, uint8_t direction,
                               uint32_t targetSteps, bool requireI2c) {
  I2CStepperDevice* device = i2c_stepper_selected_pump(); // Плата, выбранная насосом
  if (!device || !device->present) return false;
  if (speedStepsPerSecond == 0 || targetSteps == 0) return i2c_stepper_stop(*device); // Нули - остановка
  // ... проверка пределов скорости и числа шагов ...
  device->config.mode = I2CSTEPPER_V3_MODE_FILLING;
  device->motion.mode = I2CSTEPPER_V3_MODE_FILLING;
  device->motion.direction = direction;
  device->motion.speedStepsPerSec = speedStepsPerSecond;
  device->motion.targetSteps = targetSteps;
  return i2c_stepper_start_finite(*device); // Настройки, параметры движения и команда START_FINITE
}
```

Обмен с платой идёт по протоколу из библиотеки `I2CStepperV3`: ESP32 записывает блоки настроек и параметров движения, затем отправляет кадр команды с порядковым номером и ждёт, пока плата подтвердит результат. Доступ к шине I2C защищён семафором `xI2CSemaphore`. Состояние платы (в том числе остаток шагов, его возвращает `get_stepper_status()`) обновляется опросом каждые 250 мс.

### Управление основным нагревателем (мощность/напряжение)

Управление мощностью нагревательного элемента часто сложнее, чем просто вкл./выкл. Регулятор подключается к UART2 (`Serial2`, пины `RXD2`/`TXD2`) и выбирается в `Samovar_ini.h`:

*   `SAMOVAR_USE_POWER` — регулятор KVIC (скорость обмена 38400, с `KVIC_USE_9600` — 9600), код в `power_regulator_kvic.h`;
*   `SAMOVAR_USE_POWER` + `SAMOVAR_USE_RMVK` — регулятор напряжения РМВ-К (`power_regulator_rmvk.h`, `mod_rmvk.h`, `mod_rmv.ino`);
*   `SAMOVAR_USE_POWER` + `SAMOVAR_USE_SEM_AVR` — регулятор мощности SEM_AVR, уставка в ваттах (`power_regulator_sem.h`; `SAMOVAR_USE_RMVK` при этом определяется автоматически);
*   без `SAMOVAR_USE_POWER` нагрев управляется реле: реле 1 (`RELE_CHANNEL1`) — основной нагреватель, реле 4 (`RELE_CHANNEL4`) — разгонный ТЭН.

Для управления используются функции `set_current_power`, `set_power_mode` и `set_power` из `power_regulator.h`. Они не пишут в порт сами: они ставят запрос, а команду в UART отправляет отдельная задача регулятора (`triggerPowerStatus`).

```c++
// Упрощенный фрагмент из power_regulator.h
ActuatorCommandResult set_current_power(float Volt, uint64_t* generation) {
  // ... уставка ограничивается 230 В (у SEM_AVR - мощностью, эквивалентной 230 В) ...
  if (!PowerOn || heaterSafetyState.emergencyLatched) return ACTUATOR_COMMAND_FAILED; // Нагрев выключен или авария
  // Ниже порога (40 В, у SEM_AVR 100 Вт) - режим сна, иначе рабочий режим с уставкой
  const uint64_t requestGeneration = request_regulator_state_locked(
    Volt < POWER_WORK_MODE_THRESHOLD ? SAFETY_REGULATOR_MODE_SLEEP : SAFETY_REGULATOR_MODE_WORK,
    Volt >= POWER_WORK_MODE_THRESHOLD, Volt, false);
  notify_power_worker(); // Разбудить задачу регулятора
  return current_power_command_status(requestGeneration); // APPLIED, PENDING или FAILED
}

// Задача регулятора отправляет команду; формат зависит от модели.
// power_regulator_kvic.h (KVIC): "S<напряжение*10 в hex>\r"
inline bool apply_regulator_voltage_blocking(float Volt, uint64_t powerGeneration) {
  String hexString = String((int)(Volt * 10), HEX);
  const String command = "S" + hexString + "\r";
  if (!heater_uart_enqueue(UART_NUM_2, command.c_str(), command.length(), powerGeneration, true)) return false;
  target_power_volt = Volt;
  return true;
}
// РМВ-К: RMVK_set_out_voltge() -> "AT+VS=087" (три цифры, вольты)
// SEM_AVR: "АТ+VS=<уставка>\r" (префикс "АТ" из кириллических букв)

// Режим регулятора: POWER_WORK_MODE ("0"), POWER_SPEED_MODE ("1", разгон), POWER_SLEEP_MODE ("2", сон).
// KVIC: "M<режим>\r"; РМВ-К: RMVK_set_on(1/0); SEM_AVR: "АТ+ON=1\r" / "АТ+ON=0\r"
inline void set_power_mode(String Mode);

ActuatorCommandResult set_power(bool On, bool enqueueResetCommand = true) {
  if (On) {
    // Отказ с сообщением, если задача регулятора не запущена, сработала аварийная защита,
    // идёт выключение, самотест/калибровка или смена режима
    heater_outputs_enable_locked(SAFETY_HEATER_OUTPUT_MAIN, true); // PowerOn = true, реле 1 включено
    // С регулятором: через SAMOVAR_USE_POWER_START_TIME (2 с; у SEM_AVR 3 + 2 с) регулятор переводится в разгон.
    // Без регулятора: сразу включается и реле 4 (разгонный ТЭН).
  } else {
    // Реле 4 снимается сразу, через 700 мс регулятор получает команду сна,
    // ещё через 200 мс снимается реле 1 и ставится команда сброса (Глава 3)
  }
  return ACTUATOR_COMMAND_APPLIED;
}
```

Эти функции показывают, как команды высокого уровня, такие как установка целевого напряжения (`set_current_power`) или смена режима работы (`set_power_mode`), преобразуются в конкретные команды через Serial для внешнего регулятора мощности. Функция `set_power(bool On)` обеспечивает главное вкл./выкл. всего нагревательного контура, включая мастер-реле (`RELE_CHANNEL1`). Обратите внимание: команды регулятору выполняет отдельная задача, а вызывающий код получает результат (`ACTUATOR_COMMAND_APPLIED`, `ACTUATOR_COMMAND_PENDING` или `ACTUATOR_COMMAND_FAILED`); если регулятор не ответил вовремя, нагрев отключается.

### Управление другими исполнительными механизмами (реле, ШИМ, сервопривод, зуммер)

Остальные исполнительные механизмы управляются аналогично — через вызовы специализированных функций, управляющих соответствующими пинами или интерфейсами.

*   **Реле (клапан воды, мешалка, нагреватель):** Простая запись на цифровой пин. Реле 1 — нагреватель (пускатель), реле 2 — мешалка в режиме «Пиво», реле 3 — клапан воды охлаждения, реле 4 — разгонный ТЭН, если регулятор не используется.

    ```c++
    // Упрощённый фрагмент из valve_buzzer.h
    ActuatorCommandResult open_valve(bool Val, bool msg = true) {
      if (Val) {
        if (mode_switch_barrier_active) return ACTUATOR_COMMAND_FAILED; // Идёт смена режима
        digitalWrite(RELE_CHANNEL3, SamSetup.rele3); // Включить реле клапана
        valve_status = true; // Обновить флаг состояния
        // ... отправить сообщение пользователю ...
      } else {
        digitalWrite(RELE_CHANNEL3, !SamSetup.rele3); // Выключить реле клапана
        valve_status = false;
        // ... отправить сообщение пользователю ...
      }
      return ACTUATOR_COMMAND_APPLIED;
    }

    // Упрощённый фрагмент из beer.h
    void setHeaterPosition(bool state) {
      set_heater_state_flag(state); // Обновить внутренний статус
      if (state) {
    #ifdef SAMOVAR_USE_POWER
        set_current_power(SamSetup.StbVoltage); // С регулятором - задать напряжение
    #else
        heater_boost_output_off();                        // Реле 4 (разгон) выключить
        heater_enable_outputs(SAFETY_HEATER_OUTPUT_MAIN); // Реле 1 (нагреватель) включить
    #endif
      } else {
    #ifdef SAMOVAR_USE_POWER
        set_power_mode(POWER_SLEEP_MODE); // Перевести регулятор в сон
    #else
        digitalWrite(RELE_CHANNEL1, !SamSetup.rele1);
        heater_boost_output_off();
    #endif
      }
    }
    ```
*   **ШИМ (скорость насоса воды):** Использование пина с поддержкой ШИМ и установка скважности.

    ```c++
    // Упрощённый фрагмент из pumppwm.h
    ActuatorCommandResult set_pump_pwm(float duty) {
      duty = constrain(duty, 0, 1023); // Ограничить диапазон скважности (ШИМ 10 бит)
      if (duty > 0 && mode_switch_barrier_active) return ACTUATOR_COMMAND_FAILED; // Идёт смена режима
      // ... мягкий пуск: первые вызовы после включения пишут PWM_START_VALUE * 10 ...
      if (duty == 0) pump_started = false;
      pump_pwm.write(duty); // Установить скважность на пин насоса
      water_pump_speed = duty; // Сохранить текущее значение скорости
      return ACTUATOR_COMMAND_APPLIED;
    }
    ```
    Эта функция принимает заданное значение ШИМ (`duty`) и подает его на насос через объект `ESP32PWM` (библиотека `ESP32Servo`, частота `PUMP_PWM_FREQ`), регулируя его скорость. Значение подбирает ПИД-регулятор `set_pump_speed_pid()` по температуре воды.
*   **Сервопривод (распределение жидкости):** Запись значения позиции в объект сервопривода.

    ```c++
    // Фрагмент из logic.h
    void set_capacity(uint8_t cap) {
      if (cap > CAPACITY_NUM) return; // Номер емкости вне диапазона
      capacity_num = cap; // Сохранить номер текущей емкости
    #ifdef SERVO_PIN // Если используется сервомотор
      // Рассчитать целевую позицию на основе номера емкости и калибровки
      int p = ((int)cap * SERVO_ANGLE) / (int)CAPACITY_NUM + servoDelta[cap];
      servo.write(p); // Переместить сервомотор в позицию 'p'
    #elif USER_SERVO // Если используется пользовательская функция серво
      user_set_capacity(cap); // Вызвать пользовательскую функцию
    #endif
    }
    ```
    Эта функция принимает желаемый номер приемной емкости (`cap`) и перемещает подключенный сервомотор (объект `Servo` библиотеки `ESP32Servo`) в соответствующую физическую позицию.
*   **Зуммер:** Переключение цифрового выхода `BZZ_PIN`; серию сигналов отсчитывает функция, которую вызывает основной цикл `loop()`.

    ```c++
    // Упрощённый фрагмент из valve_buzzer.h
    void set_buzzer(bool fl) {
      if (fl && SamSetup.UseBuzzer) { // Включаем только если запрос и разрешено в настройках
        buzzer_active = true;         // Начать серию сигналов
        buzzer_beep_count = 0;
        buzzer_state = false;
        buzzer_next_time = millis();  // Начинаем сразу
      } else {
        buzzer_active = false;
        buzzer_beep_count = 0;
        buzzer_state = false;
        digitalWrite(BZZ_PIN, LOW);   // Убедиться, что пин LOW при выключении
      }
    }

    // Вызывается из loop() на каждом проходе
    void process_buzzer() {
      if (!buzzer_active) return;
      if ((int32_t)(millis() - buzzer_next_time) >= 0) {
        if (buzzer_state) {
          digitalWrite(BZZ_PIN, LOW);       // Выключить зуммер
          buzzer_state = false;
          if (++buzzer_beep_count >= 5) buzzer_active = false; // Серия из 5 сигналов закончена
          else buzzer_next_time = millis() + 600;              // Пауза 600 мс
        } else {
          digitalWrite(BZZ_PIN, HIGH);      // Включить зуммер
          buzzer_state = true;
          buzzer_next_time = millis() + 400; // Сигнал 400 мс
        }
      }
    }
    ```
    Функция `set_buzzer` запускает серию сигналов, а `process_buzzer` (её вызывает основной цикл `loop()`) включает и выключает зуммер по времени: пять сигналов по 400 мс с паузами 600 мс, обеспечивая звуковую обратную связь пользователю.

Эти примеры показывают, что независимо от конкретного оборудования, схема одна: основная логика вызывает функцию с параметрами высокого уровня, а эта функция реализует низкоуровневое взаимодействие (digitalWrite, ШИМ, serial-команды, I2C-сообщения), необходимое для выполнения действия исполнительным механизмом.

## Заключение

В этой главе мы познакомились с **Аппаратным управлением (Исполнительными механизмами)** — способностью Самовара физически взаимодействовать с оборудованием для варки и дистилляции. Мы рассмотрели разнообразные исполнительные механизмы, которые он использует — от нагревателей и насосов до клапанов и зуммеров — и поняли, что это "руки" и "голос" системы. Мы увидели, как логика управления, используя шаги программы ([Глава 2](02_process_program_execution_.md)), состояние системы ([Глава 3](03_system_state___mode_management_.md)) и данные датчиков ([Глава 4](04_sensor_data_acquisition_.md)), вызывает специализированные функции для управления этими механизмами. Мы рассмотрели упрощенные примеры кода для управления шаговым двигателем, нагревателем, реле, ШИМ-насосом, сервоприводом и зуммером, показав, как ПО абстрагирует сложность оборудования. Понимание управления исполнительными механизмами принципиально важно, ведь именно так Самовар переводит внутренние решения в реальные действия, автоматизируя ваш процесс.

В следующей главе мы обсудим [Мониторинг безопасности и аварии](06_safety_monitoring___alarms_.md) и узнаем, как Самовар с помощью датчиков и исполнительных механизмов предотвращает опасные ситуации и оповещает вас, если что-то идет не так.

[Глава 6: Мониторинг безопасности и аварии](06_safety_monitoring___alarms_.md)

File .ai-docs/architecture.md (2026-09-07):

# Архитектура

```mermaid
graph TD
    subgraph "Веб-интерфейс"
        WebUI[Браузер] -->|HTTP/WS| WebServer
    end

    subgraph "ESP32"
        WebServer[AsyncWebServer] -->|GET/POST| Logic
        WebServer -->|SPIFFS| FS[Файловая система]
        WebServer -->|WebSocket| WebUI

        Logic[Логика управления] -->|Lua| LuaEngine[Интерпретатор Lua]
        Logic -->|PID| HeaterControl[Управление нагревом]
        Logic -->|PWM| PumpControl[Управление насосом]
        Logic -->|GPIO| ValveControl[Управление клапаном]

        HeaterControl -->|SSR| Heater[Нагреватель]
        PumpControl -->|ШИМ| WaterPump[Насос охлаждения]
        ValveControl -->|Реле| Valve[Клапан подачи воды]

        Sensors[Датчики] -->|1-Wire| DS18B20[DS18B20]
        Sensors -->|I2C| BME280[BME280]
        Sensors -->|I2C| XGZP[XGZP6897D]
        Sensors -->|Импульсы| WF[Датчик потока]

        DS18B20 --> Logic
        BME280 --> Logic
        XGZP --> Logic
        WF --> Logic

        LCD[LCD + Энкодер] -->|I2C| Logic
        Logic -->|I2C| LCD

        LuaEngine -->|GPIO| Logic
        LuaEngine -->|I2C| I2CDevices[Расширители, шаговик]

        CrashHandler[Обработчик сбоев] -->|SPIFFS| FS
        FS -->|Загрузка| WebServer
        FS -->|Логи| WebUI
    end

    subgraph "Внешние сервисы"
        BlynkApp[Blynk] -->|Binary/HTTP| Logic
    end

    Logic -->|NVS| EEPROM[NVS хранилище]
    Logic -->|OTA| WebServer
```

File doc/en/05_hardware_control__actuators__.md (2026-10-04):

# Chapter 5: Hardware Control (Actuators)

Welcome back to the Samovar guide! In the previous chapter, [Chapter 4: Sensor Data Acquisition](04_sensor_data_acquisition_.md), we looked at how Samovar uses its sensors to "see" and collect data from the physical world – parameters such as temperature, pressure and flow rate. This real-time data gives Samovar important information about what is happening during brewing or distillation.

But merely *knowing* the temperature or the volume is not enough. Samovar is not just a monitoring device; it is a control system. It must *act*, physically interacting with the distillation or brewing equipment. It needs "hands" and a "voice" to switch things on or off, adjust power, move liquids or make sounds.

This is where **Hardware Control (Actuators)** comes into play. Actuators are the components that let Samovar physically control the installation. They are the active parts of the system that take the decisions produced by the control logic (based on program steps, system state and sensor data) and turn them into physical actions.

## Why Actuators Matter: A Use Case

Let's return to our rectification example. Suppose that Samovar, using a temperature sensor (as discussed in Chapter 4), has detected that the vapor temperature at the top of the column has reached the target value for collecting the "Hearts" (the main part of the distillate).

Knowing this temperature is useless if Samovar cannot *act* on this information. It needs to:

1.  Open a valve or switch on a pump to start collecting the liquid product.
2.  If necessary, adjust the power supplied to the heating element to maintain stable conditions.
3.  Direct the collected liquid into the right container using a distribution mechanism.
4.  Possibly even sound a buzzer to notify you of the transition to the next program step.

All of these actions are performed by **actuators**.

## Samovar's Hands and Voice: Types of Actuators

Samovar's hardware includes various actuators to perform different tasks:

*   **Heating element (controlled by a power/voltage regulator or a relay):** This is the main source of heat for the vessel. It can simply be switched on/off with a relay or, in more advanced installations, its power or voltage can be precisely regulated to maintain temperature or control the vapor rate.
*   **Cooling water valve/pump (controlled by a relay or PWM):** Controls the supply of cooling water to the condenser. It can be a simple valve (on/off via a relay) or a pump whose speed is adjusted using PWM (pulse-width modulation) based on feedback from a temperature sensor.
*   **Peristaltic pump/stepper motor (controlled by a stepper motor driver):** Used for precise control of the flow rate and total volume of collected liquid during distillation. A stepper motor provides accurate, repeatable movements — ideal for dispensing specific volumes.
*   **Stirrer motor/pump (controlled by a relay or I2C):** In brewing modes (for example, mashing) it stirs the contents of the vessel or recirculates the liquid. It is usually a simple on/off function via a relay, or control through a device on the I2C bus.
*   **Liquid distribution mechanism (controlled by a servo or relays):** Directs the collected liquid (heads, hearts, tails) into different receiving containers. It can be a servo that positions a spout, or a set of valves/relays that select the path.
*   **Buzzer (controlled by a digital output):** A simple sound alarm that notifies the user about important events (program step change, errors, etc.).

Each of these actuators is connected to Samovar's microcontroller (ESP32) through dedicated control pins or communication buses (for example, I2C or UART for power regulators). The software sends commands to these interfaces so that the actuators perform their functions.

## How Actuator Control Works

Controlling an actuator means telling it *what* to do (for example, switch on, set a speed, move to a position) and often *how much* or *how fast*. This decision-making is determined by Samovar's core logic, which combines information from the program steps ([Chapter 2](02_process_program_execution_.md)), the current system state ([Chapter 3](03_system_state___mode_management_.md)) and real-time sensor data ([Chapter 4](04_sensor_data_acquisition_.md)).

For example:
*   **Program step:** A step may require "Collect 500 ml of heads at a rate of 0.2 L/h". The program execution logic reads this, commands the stepper motor controller to move slowly for the number of steps calculated for 500 ml, and sets the container selection actuator to position 1.
*   **System state:** If the system state changes to "Heating", the control logic switches on the main heating element. If the state changes to "Alarm", heating is switched off and the buzzer is turned on.
*   **Sensor data:** If the cooling water temperature sensor reports that the water has become too hot, the valve/pump actuator may be commanded to open wider or increase its speed.

Samovar's software provides a set of functions that abstract away the low-level details of communicating with a particular actuator. These functions are the "command interface" for the actuators.

## Using Actuator Control: The Stepper Motor and Heater Example

Let's look at the control of the two most important actuators during a typical distillation program: the main heater and the liquid collection pump (the stepper motor).

According to the program steps defined in [Chapter 2](02_process_program_execution_.md), Samovar must:

1.  Switch on the main heater (usually at full power first, for warm-up).
2.  When conditions become suitable (for example, boiling starts or the column stabilizes, as determined by the sensors and state logic), reduce the heater power if necessary for stable operation.
3.  Switch on the stepper motor/pump at a certain speed and in the right direction.
4.  Track the volume of collected liquid by the number of stepper motor steps.
5.  Stop the stepper motor when the target volume for the current program step is reached.

These actions are initiated by the program execution logic calling dedicated functions to control these actuators.

## Under the Hood: The Control Flow

When Samovar decides to perform an actuator action, the command passes through the system as follows:

```mermaid
sequenceDiagram
    Program Execution->>Control Logic: Command (e.g., "Start Step 1")
    Control Logic->>Actuator Control Function: Call stepper_safe_set_target(steps), startService()
    Actuator Control Function->>Hardware Driver: GyverStepper2 + hardware timer (or I2CStepper board via I2C)
    Hardware Driver->>Physical Stepper Motor: Send step/direction pulses
    Physical Stepper Motor-->>Program Execution: (Implicitly, by changing state monitored by sensors/counters)

    Program Execution->>Control Logic: Command (e.g., "Heating State")
    Control Logic->>Actuator Control Function: Call set_current_power(voltage)
    Actuator Control Function->>Power Regulator: Power regulator task sends the command via UART2
    Power Regulator->>Physical Heating Element: Adjust power/voltage
    Physical Heating Element-->>Sensors: Changes temperature (monitored by sensors)
```

In this simplified flow:
1.  The **Program Execution** logic (or Samovar's general logic, depending on the mode/state) determines that an actuator action is required.
2.  It calls a function in the **Control Logic** layer (for example, `run_program` or `beer_stage_tick`).
3.  This control logic function calls a specific **Actuator Control Function** (for example, `stepper_safe_set_target` and `startService`, or `set_current_power`).
4.  The actuator control function contains code that interacts directly with the **Hardware Driver** (this may be a library or custom code for I2C, Serial or GPIO).
5.  The hardware driver sends the necessary signals or commands to the **Physical Actuator**, making it perform the required action.

This layered approach keeps the main program logic clean; it does not need to know the low-level details of *how* to talk to each device, only *which* function to call.

## Deep Dive into the Code

Let's look at simplified code fragments showing how Samovar controls its actuators.

### Stepper Motor Control (Peristaltic Pump)

The stepper motor plays a key role in precise liquid collection. The main collection pump is connected to the ESP32 directly (the `STEPPER_STEP`, `STEPPER_DIR`, `STEPPER_EN` pins from `Samovar_pin.h`) and is driven by the `stepper` object of the `GyverStepper2` library (`GStepper2<STEPPER2WIRE>`, declared in `Samovar.h`). Step pulses are generated by a hardware timer: `startService()` starts it, `stopService()` stops it, and its interrupt handler `StepperTicker()` calls `stepper.tickManual()`. Tasks access `stepper` only through the `stepper_safe_*` wrappers from `runtime_helpers.h`, which protect the object from simultaneous access by the interrupt.

```c++
// Simplified fragment from logic.h (run_program): starting collection for a program row
CurrrentStepperSpeed = get_speed_from_rate(program[num].Speed);      // L/h -> steps per second
TargetStepps = (uint32_t)program[num].Volume * SamSetup.StepperStepMl; // ml -> steps (pump calibration)
stepper_safe_set_max_speed(CurrrentStepperSpeed);
stepper_safe_set_current(0);           // Start counting steps from 0 for this row
stepper_safe_set_target(TargetStepps); // Set the number of steps
startService();                        // Start the timer that generates step pulses

// Simplified fragment from Samovar.ino
void startService(void) {
  // The timer period comes from the library (Arduino core 3.x; for core 2.x - timerAlarmWrite/timerAlarmEnable)
  timerAlarm(timer, stepper.getPeriod(), true, 0);
}

void IRAM_ATTR StepperTicker(void) { // Timer interrupt
  portENTER_CRITICAL_ISR(&timerMux);
  StepperMoving = stepper.tickManual(); // Make a step if it is time
  portEXIT_CRITICAL_ISR(&timerMux);
}
```

The speed (`CurrrentStepperSpeed`) and the total number of steps (`TargetStepps`) are calculated from the program row. The system tracks collection progress via `stepper_safe_get_current()`, and `set_pump_speed()` (`logic.h`) changes the speed on the fly.

A second pump and a stirrer can run on an I2CStepper board — a separate microcontroller (Arduino Nano) that drives the motor and receives commands over I2C. For it, `I2CStepper.h` provides `set_stepper_target()` (pump: a given number of steps), `set_stepper_by_time()` (stirrer: revolutions per minute for a given time) and `set_mixer_pump_target()` (relay 1 of the board).

```c++
// Fragment from I2CStepper.h
inline bool set_stepper_target(uint32_t speedStepsPerSecond, uint8_t direction,
                               uint32_t targetSteps, bool requireI2c) {
  I2CStepperDevice* device = i2c_stepper_selected_pump(); // The board selected as the pump
  if (!device || !device->present) return false;
  if (speedStepsPerSecond == 0 || targetSteps == 0) return i2c_stepper_stop(*device); // Zeros - stop
  // ... checking the speed and step count limits ...
  device->config.mode = I2CSTEPPER_V3_MODE_FILLING;
  device->motion.mode = I2CSTEPPER_V3_MODE_FILLING;
  device->motion.direction = direction;
  device->motion.speedStepsPerSec = speedStepsPerSecond;
  device->motion.targetSteps = targetSteps;
  return i2c_stepper_start_finite(*device); // Settings, motion parameters and the START_FINITE command
}
```

Communication with the board uses the protocol from the `I2CStepperV3` library: the ESP32 writes the settings and motion parameter blocks, then sends a command frame with a sequence number and waits until the board confirms the result. Access to the I2C bus is protected by the `xI2CSemaphore` semaphore. The board state (including the remaining steps returned by `get_stepper_status()`) is refreshed by polling every 250 ms.

### Main Heater Control (Power/Voltage)

Controlling the power of a heating element is often more complex than simple on/off. The regulator is connected to UART2 (`Serial2`, pins `RXD2`/`TXD2`) and is selected in `Samovar_ini.h`:

*   `SAMOVAR_USE_POWER` — the KVIC regulator (38400 baud, 9600 with `KVIC_USE_9600`), code in `power_regulator_kvic.h`;
*   `SAMOVAR_USE_POWER` + `SAMOVAR_USE_RMVK` — the RMVK voltage regulator (`power_regulator_rmvk.h`, `mod_rmvk.h`, `mod_rmv.ino`);
*   `SAMOVAR_USE_POWER` + `SAMOVAR_USE_SEM_AVR` — the SEM_AVR power regulator, setpoint in watts (`power_regulator_sem.h`; `SAMOVAR_USE_RMVK` is then defined automatically);
*   without `SAMOVAR_USE_POWER` the heating is controlled by relays: relay 1 (`RELE_CHANNEL1`) — the main heater, relay 4 (`RELE_CHANNEL4`) — the boost heating element.

Control uses the `set_current_power`, `set_power_mode` and `set_power` functions from `power_regulator.h`. They do not write to the port themselves: they queue a request, and a separate regulator task (`triggerPowerStatus`) sends the command to the UART.

```c++
// Simplified fragment from power_regulator.h
ActuatorCommandResult set_current_power(float Volt, uint64_t* generation) {
  // ... the setpoint is limited to 230 V (for SEM_AVR - to the power equivalent to 230 V) ...
  if (!PowerOn || heaterSafetyState.emergencyLatched) return ACTUATOR_COMMAND_FAILED; // Heating is off or an alarm
  // Below the threshold (40 V, 100 W for SEM_AVR) - sleep mode, otherwise work mode with the setpoint
  const uint64_t requestGeneration = request_regulator_state_locked(
    Volt < POWER_WORK_MODE_THRESHOLD ? SAFETY_REGULATOR_MODE_SLEEP : SAFETY_REGULATOR_MODE_WORK,
    Volt >= POWER_WORK_MODE_THRESHOLD, Volt, false);
  notify_power_worker(); // Wake up the regulator task
  return current_power_command_status(requestGeneration); // APPLIED, PENDING or FAILED
}

// The regulator task sends the command; the format depends on the model.
// power_regulator_kvic.h (KVIC): "S<voltage*10 in hex>\r"
inline bool apply_regulator_voltage_blocking(float Volt, uint64_t powerGeneration) {
  String hexString = String((int)(Volt * 10), HEX);
  const String command = "S" + hexString + "\r";
  if (!heater_uart_enqueue(UART_NUM_2, command.c_str(), command.length(), powerGeneration, true)) return false;
  target_power_volt = Volt;
  return true;
}
// RMVK: RMVK_set_out_voltge() -> "AT+VS=087" (three digits, volts)
// SEM_AVR: "АТ+VS=<setpoint>\r" (the "АТ" prefix is made of Cyrillic letters)

// Regulator mode: POWER_WORK_MODE ("0"), POWER_SPEED_MODE ("1", boost), POWER_SLEEP_MODE ("2", sleep).
// KVIC: "M<mode>\r"; RMVK: RMVK_set_on(1/0); SEM_AVR: "АТ+ON=1\r" / "АТ+ON=0\r"
inline void set_power_mode(String Mode);

ActuatorCommandResult set_power(bool On, bool enqueueResetCommand = true) {
  if (On) {
    // Refused with a message if the regulator task is not running, the emergency protection has tripped,
    // switching off is in progress, a self-test/calibration or a mode switch is running
    heater_outputs_enable_locked(SAFETY_HEATER_OUTPUT_MAIN, true); // PowerOn = true, relay 1 on
    // With a regulator: after SAMOVAR_USE_POWER_START_TIME (2 s; 3 + 2 s for SEM_AVR) the regulator is switched to boost.
    // Without a regulator: relay 4 (boost heating element) is switched on immediately as well.
  } else {
    // Relay 4 is released immediately, after 700 ms the regulator receives the sleep command,
    // another 200 ms later relay 1 is released and a reset command is queued (Chapter 3)
  }
  return ACTUATOR_COMMAND_APPLIED;
}
```

These functions show how high-level commands, such as setting the target voltage (`set_current_power`) or changing the operating mode (`set_power_mode`), are converted into specific Serial commands for the external power regulator. The `set_power(bool On)` function provides the master on/off for the whole heating circuit, including the master relay (`RELE_CHANNEL1`). Note that commands to the regulator are executed by a separate task, and the calling code receives the result (`ACTUATOR_COMMAND_APPLIED`, `ACTUATOR_COMMAND_PENDING` or `ACTUATOR_COMMAND_FAILED`); if the regulator does not respond in time, heating is switched off.

### Controlling Other Actuators (Relays, PWM, Servo, Buzzer)

The remaining actuators are controlled in a similar way — through calls to specialized functions that drive the corresponding pins or interfaces.

*   **Relays (water valve, stirrer, heater):** A simple write to a digital pin. Relay 1 — the heater (contactor), relay 2 — the stirrer in "Beer" mode, relay 3 — the cooling water valve, relay 4 — the boost heating element when no regulator is used.

    ```c++
    // Simplified fragment from valve_buzzer.h
    ActuatorCommandResult open_valve(bool Val, bool msg = true) {
      if (Val) {
        if (mode_switch_barrier_active) return ACTUATOR_COMMAND_FAILED; // A mode switch is in progress
        digitalWrite(RELE_CHANNEL3, SamSetup.rele3); // Switch on the valve relay
        valve_status = true; // Update the state flag
        // ... send a message to the user ...
      } else {
        digitalWrite(RELE_CHANNEL3, !SamSetup.rele3); // Switch off the valve relay
        valve_status = false;
        // ... send a message to the user ...
      }
      return ACTUATOR_COMMAND_APPLIED;
    }

    // Simplified fragment from beer.h
    void setHeaterPosition(bool state) {
      set_heater_state_flag(state); // Update the internal status
      if (state) {
    #ifdef SAMOVAR_USE_POWER
        set_current_power(SamSetup.StbVoltage); // With a regulator - set the voltage
    #else
        heater_boost_output_off();                        // Switch off relay 4 (boost)
        heater_enable_outputs(SAFETY_HEATER_OUTPUT_MAIN); // Switch on relay 1 (heater)
    #endif
      } else {
    #ifdef SAMOVAR_USE_POWER
        set_power_mode(POWER_SLEEP_MODE); // Put the regulator to sleep
    #else
        digitalWrite(RELE_CHANNEL1, !SamSetup.rele1);
        heater_boost_output_off();
    #endif
      }
    }
    ```
*   **PWM (water pump speed):** Using a PWM-capable pin and setting the duty cycle.

    ```c++
    // Simplified fragment from pumppwm.h
    ActuatorCommandResult set_pump_pwm(float duty) {
      duty = constrain(duty, 0, 1023); // Limit the duty cycle range (10-bit PWM)
      if (duty > 0 && mode_switch_barrier_active) return ACTUATOR_COMMAND_FAILED; // A mode switch is in progress
      // ... soft start: the first calls after switching on write PWM_START_VALUE * 10 ...
      if (duty == 0) pump_started = false;
      pump_pwm.write(duty); // Set the duty cycle on the pump pin
      water_pump_speed = duty; // Store the current speed value
      return ACTUATOR_COMMAND_APPLIED;
    }
    ```
    This function takes the specified PWM value (`duty`) and applies it to the pump through an `ESP32PWM` object (the `ESP32Servo` library, frequency `PUMP_PWM_FREQ`), regulating its speed. The value is chosen by the `set_pump_speed_pid()` PID controller based on the water temperature.
*   **Servo (liquid distribution):** Writing a position value to the servo object.

    ```c++
    // Fragment from logic.h
    void set_capacity(uint8_t cap) {
      if (cap > CAPACITY_NUM) return; // Container number out of range
      capacity_num = cap; // Store the current container number
    #ifdef SERVO_PIN // If a servo motor is used
      // Calculate the target position based on the container number and calibration
      int p = ((int)cap * SERVO_ANGLE) / (int)CAPACITY_NUM + servoDelta[cap];
      servo.write(p); // Move the servo motor to position 'p'
    #elif USER_SERVO // If a user-defined servo function is used
      user_set_capacity(cap); // Call the user-defined function
    #endif
    }
    ```
    This function takes the desired receiving container number (`cap`) and moves the connected servo motor (a `Servo` object of the `ESP32Servo` library) to the corresponding physical position.
*   **Buzzer:** Toggling the `BZZ_PIN` digital output; the series of beeps is timed by a function called from the main `loop()`.

    ```c++
    // Simplified fragment from valve_buzzer.h
    void set_buzzer(bool fl) {
      if (fl && SamSetup.UseBuzzer) { // Switch on only if requested and allowed in the settings
        buzzer_active = true;         // Start a series of beeps
        buzzer_beep_count = 0;
        buzzer_state = false;
        buzzer_next_time = millis();  // Start immediately
      } else {
        buzzer_active = false;
        buzzer_beep_count = 0;
        buzzer_state = false;
        digitalWrite(BZZ_PIN, LOW);   // Make sure the pin is LOW when switched off
      }
    }

    // Called from loop() on every pass
    void process_buzzer() {
      if (!buzzer_active) return;
      if ((int32_t)(millis() - buzzer_next_time) >= 0) {
        if (buzzer_state) {
          digitalWrite(BZZ_PIN, LOW);       // Switch the buzzer off
          buzzer_state = false;
          if (++buzzer_beep_count >= 5) buzzer_active = false; // A series of 5 beeps is finished
          else buzzer_next_time = millis() + 600;              // 600 ms pause
        } else {
          digitalWrite(BZZ_PIN, HIGH);      // Switch the buzzer on
          buzzer_state = true;
          buzzer_next_time = millis() + 400; // 400 ms beep
        }
      }
    }
    ```
    The `set_buzzer` function starts a series of beeps, and `process_buzzer` (called from the main `loop()`) switches the buzzer on and off by time: five 400 ms beeps with 600 ms pauses, providing audible feedback to the user.

These examples show that regardless of the specific hardware, the pattern is the same: the main logic calls a function with high-level parameters, and that function implements the low-level interaction (digitalWrite, PWM, serial commands, I2C messages) needed for the actuator to perform the action.

## Conclusion

In this chapter we got acquainted with **Hardware Control (Actuators)** — Samovar's ability to physically interact with brewing and distillation equipment. We looked at the variety of actuators it uses — from heaters and pumps to valves and buzzers — and understood that they are the "hands" and "voice" of the system. We saw how the control logic, using program steps ([Chapter 2](02_process_program_execution_.md)), system state ([Chapter 3](03_system_state___mode_management_.md)) and sensor data ([Chapter 4](04_sensor_data_acquisition_.md)), calls specialized functions to control these mechanisms. We looked at simplified code examples for controlling the stepper motor, the heater, relays, the PWM pump, the servo and the buzzer, showing how the software abstracts away the complexity of the hardware. Understanding actuator control is essential, because this is how Samovar turns internal decisions into real actions, automating your process.

In the next chapter we will discuss [Safety Monitoring and Alarms](06_safety_monitoring___alarms_.md) and learn how Samovar uses sensors and actuators to prevent dangerous situations and notify you if something goes wrong.

[Chapter 6: Safety Monitoring and Alarms](06_safety_monitoring___alarms_.md)

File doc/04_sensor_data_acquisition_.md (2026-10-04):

# Глава 4: Получение данных с датчиков

С возвращением! В предыдущих главах мы узнали, как вы взаимодействуете с Самоваром ([Глава 1: Взаимодействие с пользователем (Web & LCD)](01_user_interaction__web___lcd__.md)), как он выполняет пошаговые инструкции ([Глава 2: Исполнение программ процесса](02_process_program_execution_.md)) и как управляет своим общим состоянием и режимом ([Глава 3: Управление состоянием системы и режимами](03_system_state___mode_management_.md)).

Но как Самовар *узнаёт*, что происходит внутри труб, бака или колонны? Как он определяет, что вода уже достаточно горячая или что собран нужный объём жидкости?

Здесь на помощь приходит **Получение данных с датчиков**. Это способность Самовара собирать информацию о физическом мире с помощью своих датчиков. Представьте датчики как «глаза», «уши» и «осязание» Самовара, которые постоянно сообщают о состоянии процесса варки или дистилляции в реальном времени.

Без надёжных данных с датчиков Самовар работал бы вслепую. Он бы не знал, достигаются ли цели программы или возникла проблема, требующая внимания (например, перегрев).

## Почему датчики важны: пример использования

Представьте, что Самовар выполняет программу ректификации. Один из ключевых моментов — это достижение определённой температуры пара в верхней части колонны, что сигнализирует о начале сбора «голов» (первой, летучей фракции спирта).

Для этого Самовар должен:
1.  Иметь температурный датчик, установленный в паровом тракте.
2.  Постоянно считывать температуру с этого датчика.
3.  Сравнивать считанную температуру с целевой, заданной в шаге программы.
4.  Реагировать при достижении целевой температуры.

В этой главе мы сосредоточимся на шагах 1 и 2: как Самовар подключается к своим датчикам и получает с них данные.

## Органы чувств Самовара: типы датчиков

Самовар использует несколько видов датчиков для контроля разных аспектов процесса:

*   **Температурные датчики (DS18B20):** Это цифровые датчики, установленные в ключевых точках — пар вверху колонны, царга (примерно на 2/3 высоты), охлаждающая вода (или флегма), куб (бак, кег) и ТСА (трубка связи с атмосферой). Они передают данные о температуре в «мозг» Самовара.
*   **Датчики давления:** атмосферное давление измеряет датчик BMP180/BMP280/BME280/BME680 (выбирается при сборке прошивки, по умолчанию BME680), давление внутри системы — XGZP6897D, MPX5010D или датчик давления на шине 1-Wire. Это важно для корректировки температуры (точка кипения меняется с давлением) и для обнаружения проблем: захлёба колонны в режиме НБК и превышения предельного давления (тогда нагрев аварийно отключается).
*   **Датчик потока воды:** Измеряет скорость потока охлаждающей воды через конденсор. Критичен для обеспечения достаточного охлаждения и конденсации пара в жидкость.
*   **Датчик уровня флегмы в голове колонны (датчик P-N-P):** Включается в настройках («Использовать датчик уровня флегмы при ректификации»). Срабатывает, когда флегма поднимается до датчика, — это признак захлёба (залива) колонны; тогда Самовар снижает мощность нагрева.
*   **Датчик pH (для режима «Сыр»):** pH-зонд подключается к аналоговому входу ESP32 либо к внешнему АЦП ADS1115 по I2C (вход AIN0).

Каждый тип датчика требует немного разных аппаратных подключений и программных методов для считывания данных.

## Как происходит получение данных с датчиков

Микроконтроллер Самовара (ESP32) — как занятый учёный, одновременно собирающий данные из нескольких экспериментов. Он использует разные методы для общения с датчиками:

*   **1-Wire:** Умная система, позволяющая нескольким температурным датчикам (DS18B20) работать на одном проводе данных. Самовар отправляет команды по этому проводу для запроса температуры, а каждый датчик отвечает индивидуально по своему адресу. На этой же шине может стоять датчик давления 1-Wire: он читается так же, как температурный датчик, по своему адресу.
*   **I2C:** Ещё одна распространённая система, используемая для датчиков давления/температуры BME/BMP и XGZP6897D, АЦП ADS1115, а также для других устройств, например, дисплея (см. главу 1). Использует два провода (данные и тактирование), а устройства имеют адреса для индивидуального общения.
*   **Аналоговые или цифровые входы:** Датчик потока воды может подключаться к цифровому входу для подсчёта импульсов, а некоторые датчики давления (например, MPX5010D) или другие кастомные датчики могут отдавать аналоговое напряжение, пропорциональное измерению, которое ESP32 считывает через свой АЦП (ADC).

Чтение с датчиков происходит постоянно в фоновом режиме, пока Самовар работает. Две фоновые задачи (задача FreeRTOS — отдельный поток, который выполняется параллельно с остальной программой) опрашивают датчики через определённые интервалы: `triggerSysTicker` раз в секунду читает датчики DS18B20 и датчик потока, `triggerGetClock` примерно раз в 4–5 секунд читает датчик атмосферного давления BME/BMP и датчик давления XGZP6897D/MPX5010D.

## Хранение и доступ к данным датчиков

Куда поступают считанные данные? Программное обеспечение Самовара хранит актуальные значения датчиков в переменных, к которым легко могут обращаться другие части программы.

Для температурных датчиков Dallas (DS18B20) используется структура `DSSensor`:

```c++
// Из Samovar.h (упрощённо)
struct DSSensor {
  DeviceAddress Sensor;    // Адрес конкретного датчика на шине 1-Wire
  volatile float avgTemp;  // Последнее значение температуры (с поправками)
  float SetTemp;           // Уставка температуры, при достижении которой нужна реакция
  float BodyTemp;          // Температура, с которой начался отбор тела
  uint16_t Delay;          // Задержка включения насоса (с) при выходе температуры за уставку
  float PrevTemp;          // Предыдущее значение температуры (для отслеживания изменений)
  float Start_Pressure;    // Давление в начале отбора
  volatile int ErrCount;   // Счётчик неудачных чтений с этого датчика
  // ... другие поля ...
};

// Глобальные переменные для каждого температурного датчика
DSSensor SteamSensor;
DSSensor PipeSensor;
DSSensor WaterSensor;
DSSensor TankSensor;
DSSensor ACPSensor; // ТСА (трубка связи с атмосферой)
```

В программе определяются отдельные переменные `DSSensor` для каждой физической точки измерения (пар, царга, вода, куб, ТСА). Когда функция чтения датчиков срабатывает, она обновляет поле `.avgTemp` соответствующей переменной.

Данные других датчиков, например, давления с BME/BMP, могут храниться в более простых глобальных переменных:

```c++
// Из Samovar.h (упрощённо)
volatile float bme_temp;      // Температура с BME/BMP
volatile float bme_pressure;  // Давление с BME/BMP (в корректных единицах)
float pressure_value;         // Давление внутри системы с датчика XGZP/MPX/1-Wire (мм рт. ст.)
```
Аналогично, данные с датчика потока воды хранятся в переменных, таких как `WFflowRate` и `WFtotalMilliLitres` (WF — Water Flow, расход воды).

Большинство этих переменных (`avgTemp`, `ErrCount`, `bme_temp`, `bme_pressure`, `WFflowRate`, `WFtotalMilliLitres`) объявлены как `volatile`, аналогично переменным состояния из главы 3. Это сообщает компилятору, что их значение может меняться в любой момент (т.к. обновляется отдельной задачей), и остальные части программы всегда должны читать их актуальное значение.

## Процесс чтения данных с датчиков

Рассмотрим упрощённый алгоритм чтения и обновления данных с датчиков:

```mermaid
sequenceDiagram
    Sensor Reading Task->>Sensor Reading Task: Срабатывает по своему таймеру (раз в секунду / раз в 4–5 с)
    Sensor Reading Task->>Temperature Hardware (1-Wire): Чтение результатов и запуск следующего измерения
    Sensor Reading Task->>Pressure Hardware (I2C/Analog): Чтение сырых данных давления/температуры
    Sensor Reading Task->>Flow Hardware (Digital Input): Чтение количества импульсов

    Temperature Hardware (1-Wire)-->>Sensor Reading Task: Передаёт сырые значения температуры
    Pressure Hardware (I2C/Analog)-->>Sensor Reading Task: Передаёт сырые значения давления/температуры
    Flow Hardware (Digital Input)-->>Sensor Reading Task: Передаёт количество импульсов

    Sensor Reading Task->>Sensor Reading Task: Обработка данных (поправки, проверка ошибок)
    Sensor Reading Task->>Samovar Sensor Structures/Variables: Обновление .avgTemp, bme_pressure, WFflowRate и др.

    Samovar Sensor Structures/Variables-->>Other Samovar Logic: Предоставление актуальных данных (например, при проверке логикой программы или обновлении UI)

    Other Samovar Logic->>User Interfaces (LCD/Web): Отображение обновлённых данных с датчиков
    User Interfaces (LCD/Web)-->>User: Показ текущей температуры, давления, потока
```

Диаграмма показывает, что специальная часть системы (фоновые задачи `triggerSysTicker` и `triggerGetClock` в `Samovar.ino`) отвечает за общение с аппаратурой датчиков, получение сырых чисел, их обработку и запись итоговых значений в переменные системы. Остальные части — логика программы, веб-сервер — просто читают эти значения по мере необходимости.

## Разбор кода

Основная логика чтения температурных датчиков DS18B20 реализована в функции `DS_getvalue()` (`sensorinit.h`), которую задача `triggerSysTicker` вызывает раз в секунду.

Вот упрощённый фрагмент `DS_getvalue()`:

```c++
// Из sensorinit.h (упрощённый DS_getvalue)
void DS_getvalue(void) {
  float correctT = 0; // Поправка на атмосферное давление

  // Поправка считается, только если в настройках включено
  // «Использовать корректировку давления» и нагрев включён
  if (SamSetup.UsePreccureCorrect && bme_pressure > 0 && PowerOn) {
    correctT = (760 - bme_pressure) * 0.037;
  }

  // *** Забираем результаты измерения, запущенного в прошлом цикле ***
  float ssRaw = sensors.getTempC(SteamSensor.Sensor);
  float psRaw = sensors.getTempC(PipeSensor.Sensor);
  float wsRaw = sensors.getTempC(WaterSensor.Sensor);
  float tsRaw = sensors.getTempC(TankSensor.Sensor);
  float acpRaw = sensors.getTempC(ACPSensor.Sensor);

  // Поправка на давление - только для пара, царги и куба;
  // вода и ТСА её не получают
  float ss = correctT + ssRaw;
  float ps = correctT + psRaw;
  float ws = wsRaw;
  float ts = correctT + tsRaw;
  float acp = acpRaw;

  // (здесь же при USE_PRESSURE_1WIRE читается датчик давления 1-Wire в pressure_value)

  // Запускаем новое измерение у всех датчиков на шине 1-Wire;
  // его результаты будут прочитаны в следующем цикле, через секунду
  sensors.requestTemperatures();

  // *** Обработка значений (в коде - один цикл по пяти датчикам) ***
  // Значение ниже -10C означает ошибку (датчик не найден/отключён, -127C)
  if (ss > -10) {
    // Пользовательская калибровка (дельта) - своя у каждого датчика
    float corrected = ss + SamSetup.DeltaSteamTemp;
    // 85.0C сразу после сбоя питания датчика - заводское значение DS18B20;
    // резкий скачок к нему (>10C) не принимается, а считается ошибкой
    if (ssRaw == 85.0 && SteamSensor.avgTemp >= 2 && fabs(corrected - SteamSensor.avgTemp) > 10) {
      SteamSensor.ErrCount++;
    } else {
      SteamSensor.avgTemp = corrected;
      SteamSensor.PrevTemp = SteamSensor.avgTemp;
      SteamSensor.ErrCount = 0; // Сброс счётчика ошибок при успешном чтении
    }
  } else {
    // При ошибочном чтении — увеличить счётчик ошибок (для тревог)
    SteamSensor.ErrCount++;
  }
  // ... так же для PipeSensor (DeltaPipeTemp), WaterSensor (DeltaWaterTemp),
  //     TankSensor (DeltaTankTemp) и ACPSensor (DeltaACPTemp) ...
}
```

Этот упрощённый код показывает основные шаги:
1.  Если в настройках включена корректировка давления, рассчитывается поправка температуры по атмосферному давлению.
2.  Значения считываются с каждого датчика по его адресу (`sensors.getTempC(SensorAddress)`). Это результаты измерения, запущенного в предыдущем цикле.
3.  Всем 1-Wire датчикам отдаётся команда начать новое измерение (`sensors.requestTemperatures();`). Измерение занимает некоторое время, поэтому его результаты забираются через секунду, при следующем вызове.
4.  Для каждого успешного чтения применяется поправка на давление (`correctT`, только для пара, царги и куба) и пользовательская калибровка (`SamSetup.DeltaSteamTemp`, `SamSetup.DeltaPipeTemp` и т.д.).
5.  Итоговая температура записывается в поле `.avgTemp` структуры `DSSensor`, делая её доступной всему ПО.
6.  Если датчик не ответил корректно (температура сильно отрицательная, например, -127C, здесь < -10) или прислал скачком заводские 85C, увеличивается счётчик ошибок. Если он превысит порог — будет сгенерирована тревога ([Глава 6: Мониторинг безопасности и тревоги](06_safety_monitoring___alarms_.md)).

Чтение давления и температуры с I2C-датчика BME/BMP реализовано в функции `BME_getvalue()` (её вызывает задача `triggerGetClock`):

```c++
// Из sensorinit.h (упрощённый BME_getvalue)
void BME_getvalue(bool fl) {
  if (!bmefound) { // Проверить, инициализирован ли датчик
    bme_temp = -1;
    bme_pressure = -1;
    return;
  }

  // Используем семафор для эксклюзивного доступа к I2C-шине (см. главу 1)
  if (xSemaphoreTake(xI2CSemaphore, (TickType_t)(50 / portTICK_RATE_MS)) == pdTRUE) {
    #ifdef USE_BME280 // Для примера - ветка BME280; для BMP180/BMP280/BME680 есть свои
      // Читаем температуру и давление с датчика
      bme_temp = bme.readTemperature();
      // Переводим давление из Па в мм рт. ст. (примерно 0.75 мм рт. ст. на 100 Па)
      bme_pressure = bme.readPressure() / 100 * 0.75;
    #endif

    xSemaphoreGive(xI2CSemaphore); // Освобождаем семафор I2C-шины
  }
  // Если семафор не удалось получить (шина занята), чтение пропускается
  // до следующего цикла, а в переменных остаются прежние значения
}
```
Здесь показано, как данные читаются с I2C-устройства (неявно через библиотеку `Wire` с помощью `bme.readTemperature()` и `bme.readPressure()`) и сохраняются в глобальные переменные `bme_temp` и `bme_pressure`. Обратите внимание на использование семафора для управления доступом к I2C-оборудованию (см. главу 1). Показания BMP180 дополнительно сглаживаются фильтром (`bmp180_pressure_filter.h`), который отбрасывает одиночные выбросы давления. Датчики давления XGZP6897D и MPX5010D читает функция `pressure_sensor_get()` (там же, в `sensorinit.h`): она пишет результат в `pressure_value` в мм рт. ст. и усредняет его с прошлым значением.

Для датчика потока воды используется обработчик прерывания (ISR — функция, которую процессор вызывает сразу при появлении сигнала на входе), который считает импульсы:

```c++
// Из Samovar.ino (упрощённый ISR)
void IRAM_ATTR WFpulseCounter() {
  portENTER_CRITICAL_ISR(&waterPulseMux);
  WFpulseCount++; // Увеличиваем счётчик при каждом обнаруженном импульсе
  portEXIT_CRITICAL_ISR(&waterPulseMux);
}

// При запуске (setup_attach_water_flow_interrupt(), если включён USE_WATERSENSOR):
attachInterrupt(WATERSENSOR_PIN, WFpulseCounter, FALLING); // Настройка пина и ISR
```
Раз в секунду задача `triggerSysTicker` забирает накопленное число импульсов и обнуляет счётчик (`water_pulse_count_take()`), а функция `tick_update_water_flow()` рассчитывает скорость потока (`WFflowRate`, л/мин, с коэффициентом датчика `WF_CALIBRATION`) и общий объём (`WFtotalMilliLitres`). Если импульсов за секунду меньше `WATER_FLOW_MIN_PULSES`, поток считается нулевым.

Эти функции работают непрерывно, обеспечивая систему Самовара актуальной информацией о ходе процесса.

## Использование данных с датчиков

Где используются полученные данные? Везде!

*   **Отображение:** LCD и веб-интерфейсы ([Глава 1: Взаимодействие с пользователем (Web & LCD)](01_user_interaction__web___lcd__.md)) постоянно показывают значения `avgTemp`, `bme_pressure`, `WFflowRate` и др., чтобы вы могли наблюдать за процессом.
*   **Выполнение программы:** Логика определения завершения шага ([Глава 2: Исполнение программ процесса](02_process_program_execution_.md)) сильно зависит от данных датчиков. Например, сравнение `SteamSensor.avgTemp` с целевой температурой или числа сделанных шагов насоса отбора (`CurrrentStepps`) с `TargetStepps` (так отслеживается отобранный объём).
*   **Управление состоянием:** Строку общего статуса раз в секунду обновляет `tick_status_fsm()` (`logic.h`, см. главу 3); она опирается на показания датчиков для индикации фаз типа «Разгон колонны» или «Стабилизация».
*   **Мониторинг безопасности:** Тревоги ([Глава 6: Мониторинг безопасности и тревоги](06_safety_monitoring___alarms_.md)) срабатывают при превышении безопасных лимитов (например, `WaterSensor.avgTemp >= MAX_WATER_TEMP`).
*   **Алгоритмы управления:** PID-регулятор нагревателя ([Глава 5: Аппаратное управление (исполнители)](05_hardware_control__actuators__.md)) использует значение температуры выбранного в программе датчика (например, `TankSensor.avgTemp`) как «вход» для расчёта мощности.
*   **Логирование:** Данные датчиков во время процесса каждые 4 секунды отправляются строкой лога на сервер и каждые 16 секунд сохраняются в файл ([Глава 7: Сохранение настроек и журналирование](07_configuration_persistence_.md)) для последующего анализа.

Постоянно обновляя значения датчиков, Самовар поддерживает актуальную картину процесса, что позволяет принимать обоснованные решения и оперативно реагировать на изменения.

## Заключение

В этой главе мы изучили, как Самовар получает информацию из физического мира посредством **получения данных с датчиков**. Мы рассмотрели различные типы используемых датчиков (температура, давление, поток, уровень, pH) и методы их опроса (1-Wire, I2C, цифровые/аналоговые входы). Мы увидели, как полученные данные сохраняются в специальных структурах и переменных, делая их доступными для всех частей системы. Также были разобраны упрощённые примеры кода по считыванию, корректировке и обновлению температурных и давленческих показаний. Понимание принципов получения данных с датчиков фундаментально важно, ведь именно на этих данных строится выполнение программ, управление состоянием, системы безопасности и алгоритмы управления Самовара.

В следующей главе мы перейдём от сенсорики к **Аппаратному управлению (исполнители)**, чтобы узнать, как Самовар использует данные с датчиков и логику программы для выполнения действий — включения нагревателей, запуска насосов или открытия клапанов.

[Глава 5: Аппаратное управление (исполнители)](05_hardware_control__actuators__.md)

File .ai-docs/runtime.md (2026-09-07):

# Запуск и окружение

## Требования к окружению

Для сборки и запуска прошивки "Самовар" требуется:

- **Платформа**: ESP32 (поддерживаются модели: DEVKIT, LILYGO T-RELAY, ESP32S3).
- **Среда разработки**: PlatformIO (рекомендуется) или Arduino IDE.
- **Фреймворк**: Arduino Core для ESP32.
- **Файловая система**: LittleFS или SPIFFS (настраивается через `USE_LittleFS`).
- **Память**: Минимум 4 МБ Flash, из которых до 1.6 МБ выделяется под прошивку (настраивается в `partitions/samovar.csv`).

## Конфигурация сборки

Основная конфигурация задаётся в `platformio.ini`:

```ini
[env:Samovar]
platform = espressif32
board = doit-devkit-v1
framework = arduino
build_type = release
build_flags = -Os -ffunction-sections -fdata-sections -Wl,--gc-sections
board_build.f_cpu = 240000000L
board_build.f_flash = 80000000L
board_build.flash_mode = dio
monitor_speed = 115200
lib_ignore = *
lib_deps = ...
```

Ключевые параметры:
- `build_type = release` — сборка с оптимизацией размера.
- `board_build.f_cpu = 240000000L` — частота CPU 240 МГц.
- `monitor_speed = 115200` — скорость отладочного порта.
- `lib_ignore = *` — игнорирование стандартных библиотек, подключение только указанных.

## Аппаратная конфигурация

Распиновка задаётся в `samovar_pin.h`. Автоматически определяется тип платы по макросам Arduino. Поддерживаются:
- `ESP32S3`
- `LILYGO T-RELAY`
- `ESP32 DEVKIT` (по умолчанию)

Пример конфигурации для DEVKIT:
```c
#define ONE_WIRE_BUS 15
#define STEPPER_STEP 26
#define STEPPER_DIR 27
#define STEPPER_EN 14
#define RELE_CHANNEL1 2
#define RELE_CHANNEL2 4
#define RELE_CHANNEL3 16
#define RELE_CHANNEL4 17
#define ENC_CLK 34
#define ENC_DT 35
#define ENC_SW 32
#define LCD_SDA 21
#define LCD_SCL 22
#define LCD_ADDRESS 0x27
```

## Условная компиляция

Функциональность включается через макросы в `Samovar_ini.h` и `user_config_override.h`:

| Макрос | Назначение |
|---|---|
| `USE_LUA` | Включение интерпретатора Lua |
| `USE_WEB_SERIAL` | Включение WebSerial |
| `SAMOVAR_USE_BLYNK` | Поддержка Blynk |
| `USE_WATER_PUMP` | Управление водяным насосом |
| `USE_STEPPER_ACCELERATION` | Ускорение шагового двигателя |
| `USE_CRASH_HANDLER` | Обработчик сбоев и стектрейсов |
| `USE_UPDATE_OTA` | OTA-обновления |

## Инициализация системы

При старте выполняется:
1. **Миграция данных**: Перенос настроек из EEPROM в NVS (если флаг миграции ≤ 250).
2. **Загрузка конфигурации**: Чтение `SamSetup` из NVS, применение значений по умолчанию при отсутствии.
3. **Инициализация периферии**:
   - Датчики температуры (DS18B20), давления (BME, XGZ).
   - Дисплей (LiquidCrystal_I2C), энкодер (GyverEncoder).
   - Реле, шаговый двигатель, сервопривод.
4. **Подключение к Wi-Fi**: В режиме STA или AP (если нет сохранённых данных).
5. **Запуск сервисов**:
   - mDNS (`samovar.local`).
   - AsyncWebServer.
   - Blynk (если включено).
   - Lua-интерпретатор (если `USE_LUA`).
   - NTP-синхронизация времени.

## Запуск прошивки

1. Соберите проект в PlatformIO.
2. Прошейте устройство через USB.
3. При первом запуске:
   - Устройство создаст AP `Samovar-XXXX` с паролем `admin`.
   - Подключитесь к AP и откройте `http://192.168.4.1`.
   - Настройте Wi-Fi в портале `AsyncWiFiManager` — он открывается сам, таймаут 360 с.
4. После подключения к сети — доступ по `http://samovar.local` или IP-адресу.

## Отладка и мониторинг

- **Серийный порт**: Вывод отладочных сообщений на скорости 115200 бод.
- **WebSerial**: Доступен при `USE_WEB_SERIAL`.
- **Веб-интерфейс**: Мониторинг через `/` (автоматическое определение режима).
- **Логи**: Запись в `data.csv` на SPIFFS/LittleFS.
- **Сбои**: При `USE_CRASH_HANDLER` — сохранение стектрейса в `/crash.txt`.

## Обновление прошивки

Поддерживается OTA-обновление:
- Адрес: `http://samovar.local/update`.
- Файл: `firmware.bin`.
- Во время обновления отключаются Blynk и Lua для снижения нагрузки.
- Таймаут: 30 секунд.

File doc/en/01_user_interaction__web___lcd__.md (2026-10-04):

# Chapter 1: User Interaction (Web Interface and LCD)

Welcome to the Samovar tutorial! The first chapter is about how you, the user, can interact with the Samovar system for brewing and distillation. Think of Samovar as a complex machine, and of the user interaction interfaces as its dashboard and control panel. They let you see what Samovar is doing, check its state, and give it commands to perform various tasks.

Whether you are simply monitoring the temperature or setting up a complex brewing program, you need a way to communicate with Samovar. This is where the user interfaces come in. Samovar provides two main ways to do this:

1.  **Physical interface:** a built-in LCD with buttons and a rotary encoder (the kind of rotating knob you may have seen).
2.  **Web interface:** a control panel that you can access from a web browser on your computer or smartphone connected to the same network.

Let's imagine a simple task: you want to see the current temperature inside the brewing vessel, and then start a pre-programmed brewing process. Both the LCD and the web interface let you do this.

## Physical Interface: LCD and Buttons

The LCD shows important information directly on the Samovar device. Next to the screen there are buttons or a rotary encoder. These physical controls let you navigate the menus, browse the different screens, and make simple selections or settings.

### Viewing Information on the LCD

Samovar uses the LCD to display real-time data. This includes sensor readings such as temperature, the current process status, timers and menu options.

Here is a quick look at how the system defines what is shown on the LCD (using the `LiquidCrystal_I2C` and `LiquidMenu` libraries):

```c++
// From Menu.ino
LiquidLine lql_steam_temp(0, 0, str_Steam_T, SteamSensor.avgTemp);
LiquidLine lql_pipe_temp(0, 1, str_Pipe_T, PipeSensor.avgTemp);
LiquidLine lql_water_temp(0, 2, str_Water_T, WaterSensor.avgTemp);
LiquidScreen main_screen(lql_steam_temp, lql_pipe_temp, lql_water_temp, lql_time);
```

This snippet shows how "lines" of text (`LiquidLine`) are defined, linking descriptive text (for example, "Steam T:") with sensor data (for example, `SteamSensor.avgTemp`). These lines are then grouped into "screens" (`LiquidScreen`). Here `main_screen` is set up to show the steam, column (pipe) and water temperatures, as well as the current time. The LCD library (`LiquidCrystal_I2C`) is responsible for actually drawing this text on the screen.

The system must regularly refresh what is shown on the LCD:

```c++
// From Menu.ino
void menu_update() {
  LcdLockGuard lcdLock;                // Takes xI2CSemaphore for LCD_UPDATE_TIMEOUT ms
  if (lcdLock) main_menu1.update();    // This tells the menu system to refresh the display
}                                      // The semaphore is released automatically on exit
```

This function is called repeatedly to keep the information on the LCD up to date. The `LcdLockGuard` object manages access to the display: its constructor takes the `xI2CSemaphore` semaphore (`xSemaphoreTake`), and it gives it back by itself when the function exits (`xSemaphoreGive`). This way different parts of the program do not try to use the LCD and the I2C bus at the same time, which could cause problems. If the semaphore is busy for longer than `LCD_UPDATE_TIMEOUT` (200 ms), the screen update is simply skipped.

### Control with Buttons/Encoder

Physical buttons or, more commonly, a rotary encoder with a push button are used to interact with the menu on the LCD.

The rotary encoder lets you:
* Turn it left or right to move through menu items or change values.
* Press the button (click) to select an item or confirm a change.

The code constantly checks for the following actions:

```c++
// From Menu.ino (simplified; before the call, loop() polls the encoder with encoder.tick())
void encoder_getvalue() {
  if (encoder.isRight()) {
    // The user turned right -- possibly go to the next screen or increase a value
    if (!main_menu1.is_callable(1)) { // If the current item is not clickable...
      menu_next_screen(); // ...go to the next screen
    } else {
      main_menu1.call_function(1); // ...otherwise execute the associated function (for example, increase a value)
    }
  } else if (encoder.isLeft()) {
    // The user turned left -- possibly go to the previous screen or decrease a value
    if (!main_menu1.is_callable(2)) { // If the current item is not clickable...
      menu_previous_screen(); // ...go to the previous screen
    } else {
      main_menu1.call_function(2); // ...otherwise execute the associated function (for example, decrease a value)
    }
  } else if (encoder.isRightH() || encoder.isLeftH()) {
    // Turning with the button held down -- the same value change, but with a 10 times larger step
    multiplier = 10;
    main_menu1.call_function(encoder.isRightH() ? 1 : 2);
  } else if (encoder.isClick()) {
    // The user pressed the button -- select the current option or change focus
    menu_switch_focus();
  }
  // ... periodic screen updates also happen here ...
}
```
The `encoder_getvalue` function reads the encoder state. Depending on whether it was turned left/right or pressed, it either moves between screens (`menu_next_screen`, `menu_previous_screen`) or calls a specific function associated with the currently selected item (`main_menu1.call_function`). For example, turning right on a temperature setting can call a function that increases the target temperature. A click can switch the focus to allow editing the value. During calibration of the withdrawal pump, turning the encoder changes the stepper motor speed, and a click ends the calibration.

To start our imaginary process using the LCD, we would navigate the screens with the encoder until we find the ">Start:" line, and then press the button. This runs the `menu_samovar_start()` function. It works only in rectification mode and only when the power (heating) is on.

## Web Interface

The web interface provides a richer and more visual way to interact with Samovar. You can access it through a web browser (for example, Chrome, Firefox, Safari) by entering the IP address of Samovar. This interface often shows the information from the LCD, but may include additional features such as charts, detailed settings and easy program editing.

### Viewing Information on the Web

The web interface displays sensor data, status messages, program progress and various system parameters. It is like a full control panel on your computer or phone.

The data displayed on the web comes from Samovar, which sends information, usually in a structured format such as JSON, to the web page running in your browser. The web page then updates its display using this data.

```c++
// From WebServer.ino
server.on("/ajax", HTTP_GET, [](AsyncWebServerRequest *request) {
  send_ajax_json(request); // Collect the current data and send it to the browser as JSON
});
```

This snippet shows part of the web server code. When the browser requests the `/ajax` address (this happens periodically in the background on the web page, with a request like `/ajax?messageCursor=…`), Samovar calls the `send_ajax_json()` function (it is located in `Samovar.ino`). The function takes a snapshot of the latest data (temperatures, status, etc.) and sends it to the browser as JSON (a response of type `application/json`), together with the new messages that appeared after the `messageCursor` number. The browser updates the web page elements with the new values. The initial data (mode, settings, program) is loaded by the page when it opens, with a single `/ui-bootstrap` request.

The web pages themselves (such as `index.htm` and `chart.htm`) are stored in the internal Samovar file system (LittleFS; the code accesses it through the name `SPIFFS`) and served by the web server.

```c++
// From WebServer.ino
server.on("/index.htm", HTTP_GET, [](AsyncWebServerRequest *request) {
  send_index_page(request); // Send the page of the current mode
}).addMiddleware(&headerFilter);
server.serveStatic("/chart.htm", SPIFFS, "/chart.htm").setCacheControl("max-age=1").addMiddleware(&headerFilter);
server.serveStatic("/setup.htm", SPIFFS, "/setup.htm").setTemplateProcessor(setupKeyProcessor).setCacheControl("max-age=1").addMiddleware(&headerFilter);
// ... other files such as style.css, images ...
```

This tells the web server that when the browser requests `/chart.htm` or `/setup.htm`, it should send the corresponding file from its storage. For a `/index.htm` request, the `send_index_page()` function sends the page of the current mode: `index.htm` for rectification, sous vide and Lua, and `distiller.htm`, `beer.htm`, `bk.htm`, `nbk.htm` or `cheese.htm` for the other modes. The `.setTemplateProcessor(setupKeyProcessor)` part of the settings page is interesting -- it means that the server replaces placeholders in the HTML file (such as `%SteamColor%` or `%WProgram%`) with values from the current Samovar settings *before* sending the file to the browser. This lets the settings page load with the right values. The other pages do not use templates: they get their data through the `/ui-bootstrap` and `/ajax` requests.

### Control via the Web

The web interface has buttons, input fields and drop-down lists that let you send commands and update settings.

When you click a button or change a value on a web page, your browser sends a request back to the Samovar web server.

```c++
// From WebServer.ino
server.on("/command", HTTP_POST, [](AsyncWebServerRequest *request) {
  web_command(request); // Handle the command from the web request
});
server.on("/program", HTTP_POST, [](AsyncWebServerRequest *request) {
  web_program(request); // Handle program updates
});
server.on("/save", HTTP_POST, [](AsyncWebServerRequest *request) {
  handleSave(request); // Handle saving configuration settings
});
// ... other command handlers ...
```

These lines tell the web server what to do when it receives POST requests to `/command`, `/save` or `/program`. For example, clicking the "Start" button on a web page sends a POST request to `/command` with the body `start=1` (this is done by the `sendCommandRequest` function in `app.js`). The `web_command` function then checks the request for parameters such as `start=1` and converts them into an action that Samovar must perform.

In our case, clicking the "Start" button on the web page runs the `web_command` function, which puts the start command of the current mode into the queue (`queue_samovar_command(mode_start_command(Samovar_Mode))`; for rectification it is `SAMOVAR_START`), telling the main Samovar logic to begin the process.

## How It Works Under the Hood

Let's trace how a user action, such as starting a process, passes through the Samovar system.

When you interact with either interface, the basic idea is the same:
1.  **Input detection:** The interface (the LCD code or the web server code) detects the user's action (an encoder click, a button press, a web request).
2.  **Translate into a command:** The interface code translates this physical action or web request into a specific command or parameter change understood by the main Samovar control logic.
3.  **Command execution:** The main Samovar logic receives the command and performs the corresponding action (for example, turns on the heater, starts a pump, changes a setting).
4.  **Update state:** The internal state and data of Samovar are updated based on the action.
5.  **Interface update:** Samovar informs both the LCD and the web interface about the new state and data, so that they can show the user what is happening.

Here is a simplified sequence of actions:

```mermaid
sequenceDiagram
    User->>LCD/Web: Performs Action (e.g., Click «Start»)
    LCD/Web->>Interface Handler: Detects Action
    Interface Handler->>Samovar Logic: Sends Command (e.g., SAMOVAR_START)
    Samovar Logic->>Samovar Logic: Executes Process (e.g., turns on heater)
    Samovar Logic->>Samovar Logic: Updates Internal State/Data
    Samovar Logic->>Interface Handler: Notifies of State/Data Change
    Interface Handler->>LCD/Web: Updates Display (New Status/Data)
    LCD/Web->>User: Shows Updated Information
    Note over LCD/Web: This cycle repeats continuously<br/>for monitoring and control.
```
The `Interface Handler` block represents the code responsible for managing the LCD menu (`Menu.ino`) and the web server (`WebServer.ino`). These handlers interact with `Samovar Logic`, which contains the core state machine and the control algorithms of the brewing/distillation process (covered in chapters such as [Process Program Execution](02_process_program_execution_.md) and [System State & Mode Management](03_system_state___mode_management_.md)).

## Key Code Points for Working with the Interfaces

The `Menu.ino` file is intended for working with the LCD and the encoder. It defines the screens and lines, and also defines the functions that are called when the encoder is used while a particular line is selected.

For example, this function is associated with the "Start" line on one of the main screens:

```c++
// From the Menu.ino file (simplified)
void menu_samovar_start() {
  // The function works only in rectification mode and with the power on
  if (Samovar_Mode != SAMOVAR_RECTIFICATION_MODE || !PowerOn) return;
  String Str;

  // Logic for determining the next program step
  if (startval == SAMOVAR_STARTVAL_RECT_DONE) startval = SAMOVAR_STARTVAL_RECT_STOPPING;
  else if (ProgramNum >= ProgramLen - 1 && startval != SAMOVAR_STARTVAL_IDLE)
    startval = SAMOVAR_STARTVAL_RECT_DONE;

  // Based on the current state (startval), decide what to do
  if (startval == SAMOVAR_STARTVAL_IDLE) {
    // Initial start: check the program, create the log file, open a session
    Str = "Prg No 1";
    // ... if validate_rect_program_startable() or create_data() fails, the start is cancelled ...
    session_begin(sessionDescription);
    run_program(0); // Execute the first program line
    ProgramNum = 0;
    startval = SAMOVAR_STARTVAL_RECT_RUNNING;
  } else if (startval == SAMOVAR_STARTVAL_RECT_RUNNING) {
    // Move to the next program line
    ProgramNum++;
    Str = "Prg No " + (String)(ProgramNum + 1);
    run_program(ProgramNum);
  } else if (startval == SAMOVAR_STARTVAL_RECT_DONE) {
    // The program is complete
    Str = "Prg finish";
    // ... run_program(PROGRAM_END) or "self-run" until automatic power-off ...
  } else {
    // Stop the process
    Str = "Stoped";
    run_program(PROGRAM_END); // Special "end of program" number for stopping
    reset_sensor_counter();
  }
  // Update the text shown on the LCD
  copyStringSafe(startval_text_val, Str);
  // Update the LCD
  reset_focus();
  menu_update();
}
```

This function is called when the user navigates to the "Start" option on the LCD with the encoder and presses the button (it is also called by a separate start button, if one is connected). It checks the current state (`startval`, `ProgramNum`) and decides whether to start, continue or stop the program by calling `run_program()` (a function described in detail in [Process Program Execution](02_process_program_execution_.md)). If the program is complete and `PROGRAM_DONE_AUTO_POWEROFF_MIN` is greater than zero, the withdrawal stops but the heating stays on ("self-run") until automatic power-off or the next press. Finally, it updates the text shown on the LCD and refreshes the screen.

The `WebServer.ino` file handles all web interactions. It sets up the endpoints (URLs) that the browser can interact with.

```c++
// From the WebServer.ino file (simplified)
void web_command(AsyncWebServerRequest *request) {
  // The request must contain exactly one POST parameter with an allowed command name
  if (!get_web_command_action(request, action, actionParam)) {
    send_web_command_response(request, 400, "BAD_REQUEST");
    return;
  }
  // ... checking the parameter value (numbers, 0/1) ...

  // Protection against accidental double clicks: the same command repeated within 1.5 s is ignored
  if (commandKey == last_command_key && millis() - last_command_time < 1500) {
    send_web_command_response(request, 429, "IGNORED");
    return;
  }

  if (action == "start") {
    // Starting is possible only with the power on
    if (!PowerOn) {
      send_web_command_response(request, 409, "POWER_OFF");
      return;
    }
    // The start command depends on the mode (for rectification it is SAMOVAR_START)
    if (!queue_samovar_command(mode_start_command(Samovar_Mode))) {
      send_web_command_response(request, 503, "BUSY");
      return;
    }
  } else if (action == "power") {
    // power=1 -- turn on (each mode has its own power-on command), power=0 -- turn off
    SamovarCommands command = SAMOVAR_NONE;
    if (boolValue) {
      if (!PowerOn) command = mode_power_on_command(Samovar_Mode);
    } else {
      command = SAMOVAR_POWER_OFF;
    }
    if (command != SAMOVAR_NONE && !queue_samovar_command(command)) {
      send_web_command_response(request, 503, "BUSY");
      return;
    }
  }
  // ... handlers for other commands such as reset, calibration, pause, etc. ...
  send_web_command_response(request, 200, "OK"); // Send a simple response to the browser
}
```

This `web_command` function receives a web request. It checks the parameter in the body of the POST request (for example, `start=1`). Based on the parameter found, it puts a command (a `SamovarCommandMsg` message) into the `samovar_command_queue` queue via `queue_samovar_command(...)`. The main `loop()` in `Samovar.ino` takes commands from the queue with the `receive_samovar_command()` function and performs the corresponding action. The server answers the browser with a short code word (`OK`, `BUSY`, `IGNORED`, `POWER_OFF`, etc.), and the page itself picks the user-friendly text for that code. This is a common pattern for interaction between different tasks or parts of code in embedded systems.

The web interface also allows saving configuration settings, which is handled by the `handleSave` function (it is not shown in full here, but it reads the parameters from the POST request, checks them and updates the `SamSetup` structure), and editing the program, which is handled by `web_program`.

## Conclusion

In this chapter we looked at two ways of interacting with Samovar: the physical LCD with its controls, and the flexible web interface. Both interfaces let you monitor the system state and sensor data and, most importantly, send commands to control the brewing or distillation process, for example, to start a program. We looked at simplified code examples showing how sensor data is displayed, how user input (from encoder presses or web requests) is recognized and converted into commands for the main Samovar logic.

Understanding these interfaces is the first step toward controlling Samovar. In the next chapter we will look in more detail at how Samovar executes the programs you select or define.

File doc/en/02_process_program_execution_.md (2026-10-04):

# Chapter 2: Process Program Execution

Welcome to the Samovar tutorial! In [Chapter 1: User Interaction (Web and LCD)](01_user_interaction__web___lcd__.md) we learned how you can tell Samovar what to do using its physical or web interface. Now let's look at what happens *after* you press the "Start" («Старт») button or select a program: how Samovar automatically executes a sequence of steps to carry out your brewing or distillation process.

Imagine you are following a recipe. A recipe is not just a single instruction, it is a list of steps: "Heat the water to X degrees", "Add ingredient Y and stir for Z minutes", "Hold the temperature at A degrees for B hours", and so on. Each step has certain requirements (temperature, time, action).

The Samovar project deals with complex processes such as spirit distillation (rectification, distillation, NBK) or beer brewing (wort preparation stages, boiling). These processes also require following an exact sequence of steps with specific parameters. Controlling everything manually as the process goes on would be incredibly tedious and would require constant attention.

This is where **Process Program Execution** comes in. It is like an automated chef who follows your recipe exactly.

## What Is a Process Program?

In Samovar, a "program" is simply a stored list or sequence of steps. Each step in the program tells Samovar to perform a specific action with specific parameters until a given condition is met.

Think of a program as a spreadsheet or a list of instructions for Samovar. For example, a step in a "Rectification" program might look like this:

* **Type:** Heads collection
* **Volume:** 100 ml
* **Speed:** 0.1 l/h
* **Target temperature:** (optional, often based on the previous step)
* **Collection vessel:** Container 1
* **Heater power:** 120 V (or the equivalent percentage/power)

A step in a "Beer" program might look like this:

* **Type:** Temperature rest (mashing step)
* **Target temperature:** 65°C
* **Duration:** 60 minutes
* **Mixer/pump:** Runs periodically
* **Heater power:** Controlled by PID to maintain the temperature
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

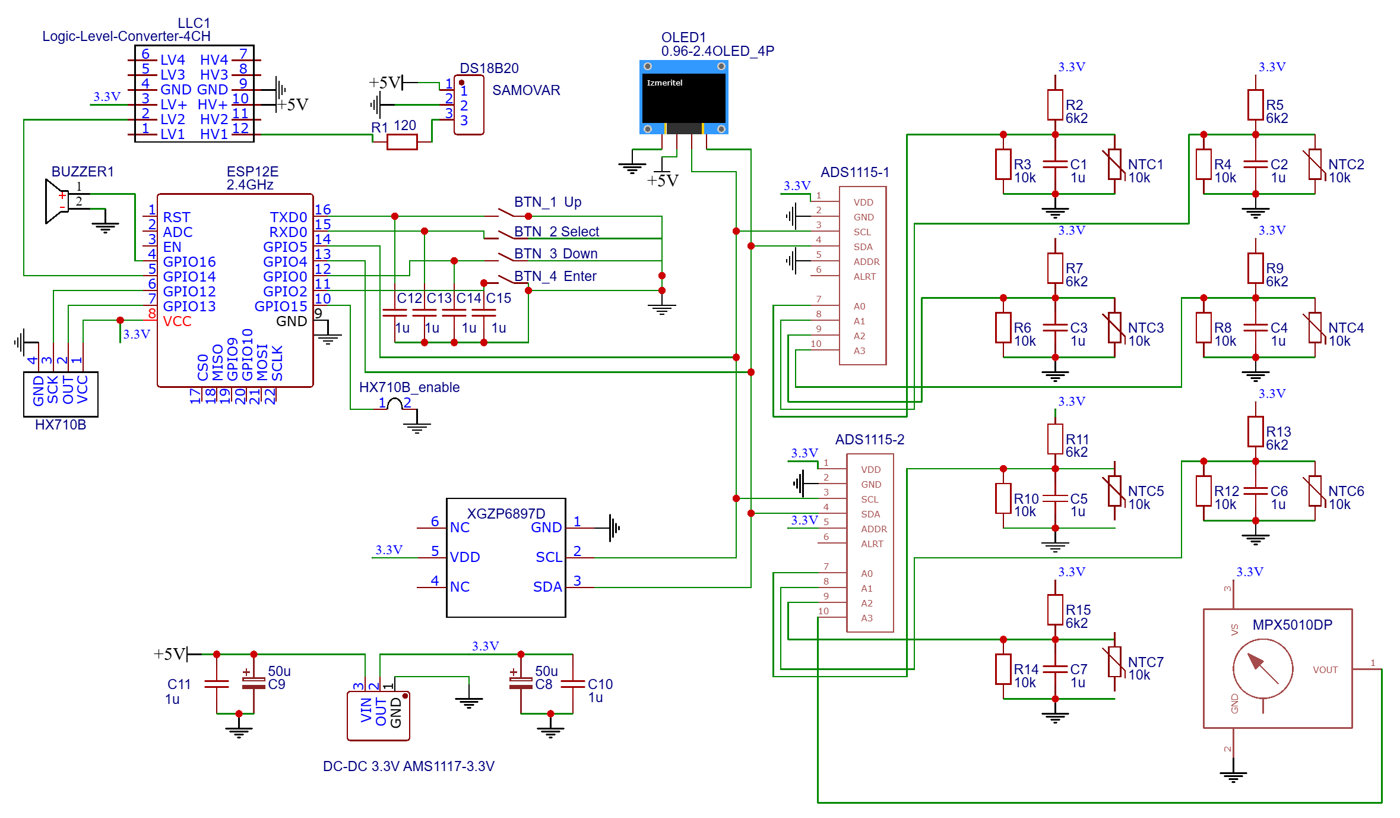
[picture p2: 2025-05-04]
pro_mini_ntc/Схема и плата/Schematic_Izmeritel-esp12e_2025-04-15.png

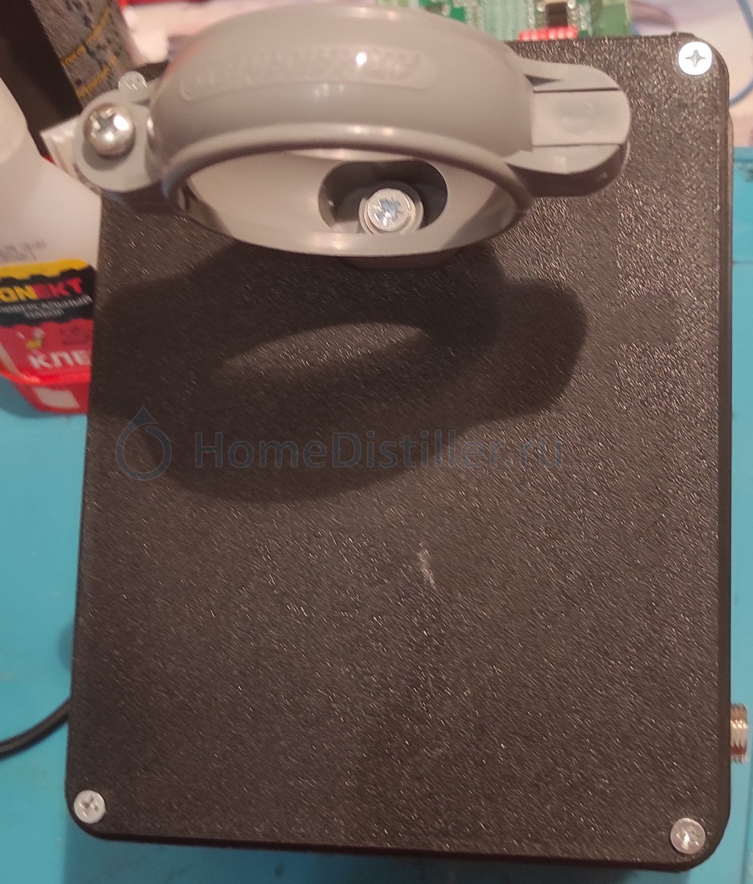
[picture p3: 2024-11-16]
3D/Samovar Box by dranek/Image/Samovar Box 4.jpg

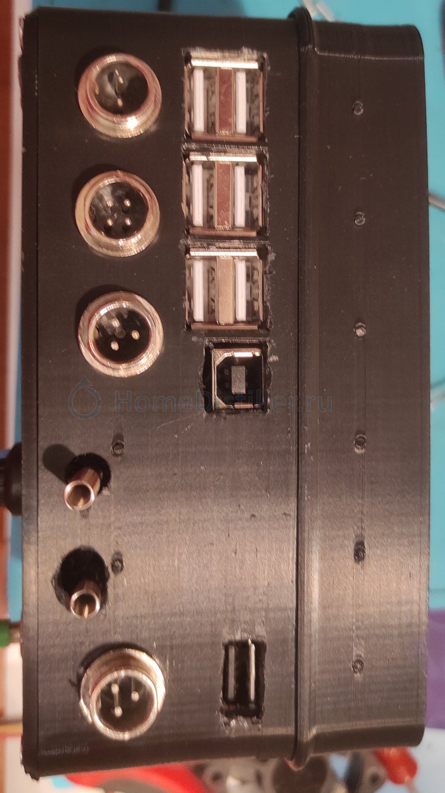
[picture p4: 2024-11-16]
3D/Samovar Box by dranek/Image/Samovar Box 6.jpg

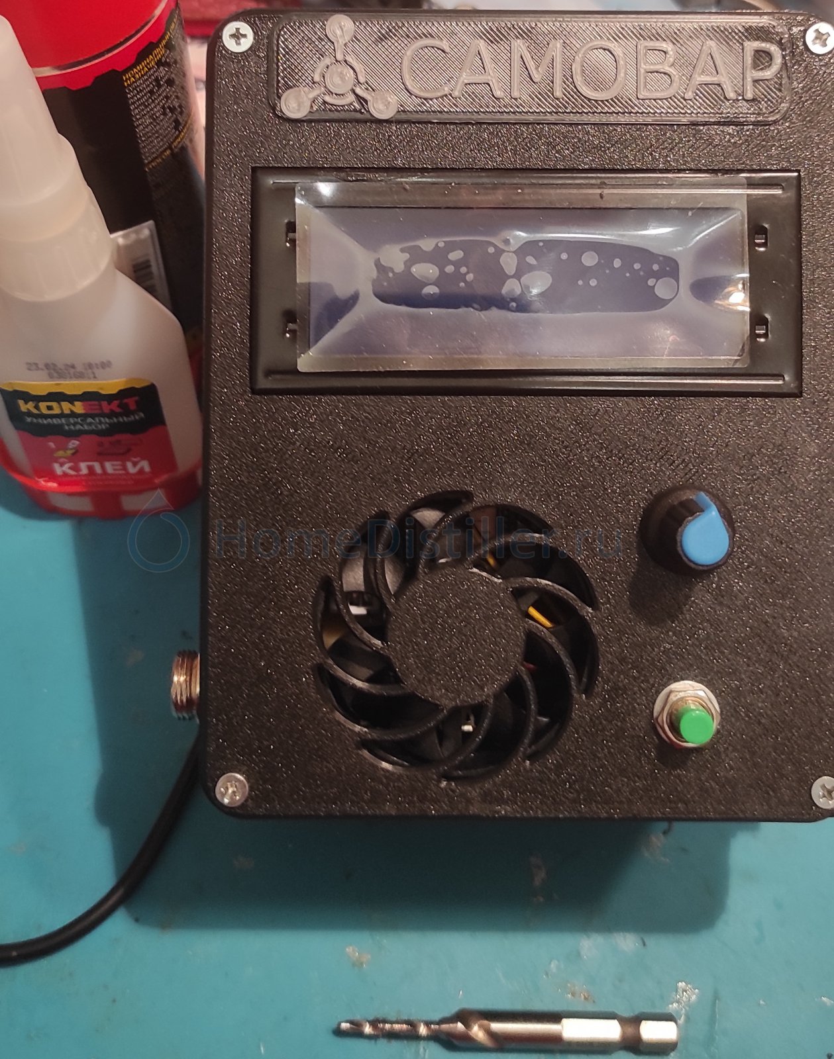
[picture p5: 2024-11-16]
3D/Samovar Box by dranek/Image/Samovar Box 3.jpg

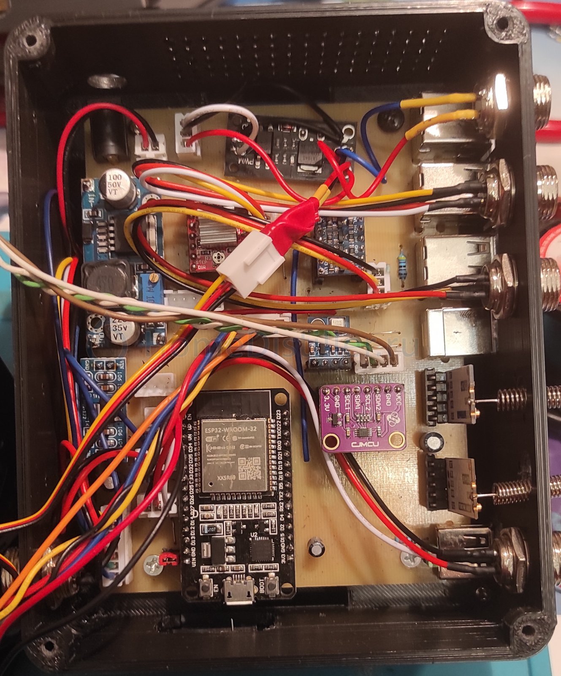
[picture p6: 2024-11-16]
3D/Samovar Box by dranek/Image/Samovar Box 2.jpg

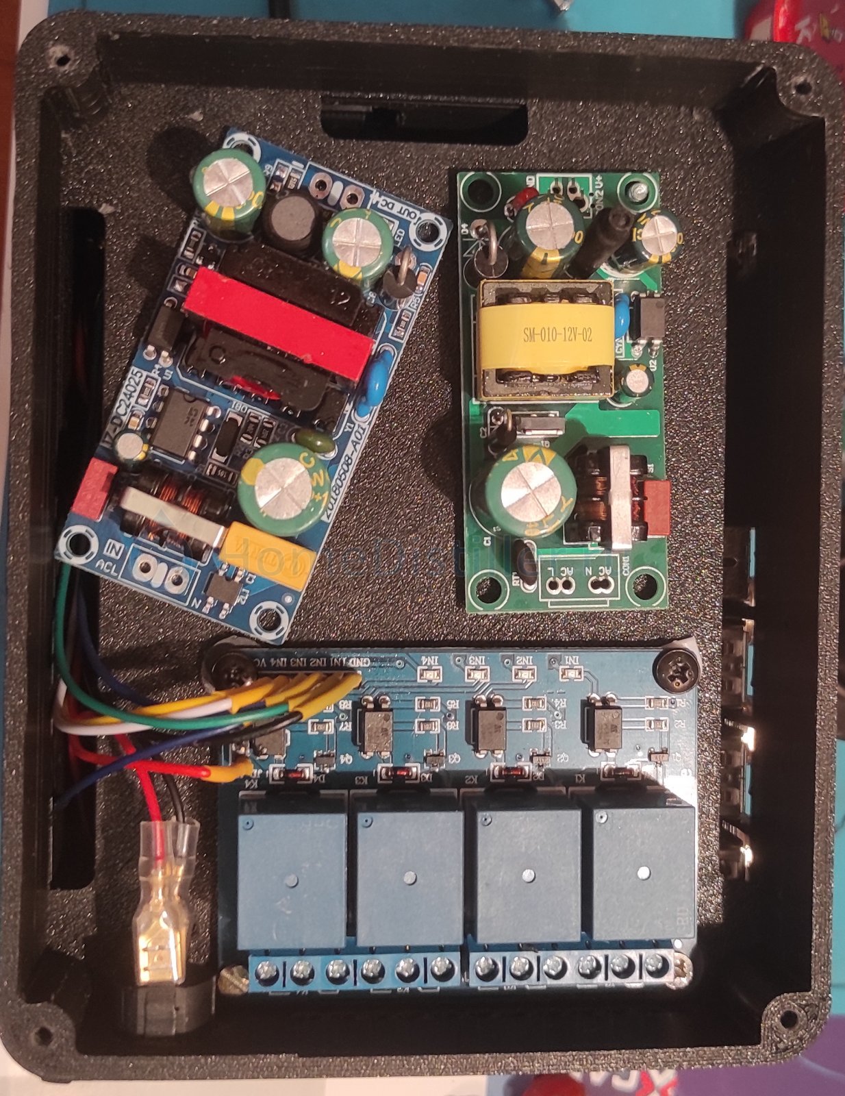
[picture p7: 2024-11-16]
3D/Samovar Box by dranek/Image/Samovar Box 5.jpg

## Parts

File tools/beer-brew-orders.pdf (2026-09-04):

# Варочные порядки в Самоваре

Варочный порядок — это схема пивоварни, а не рецепт. Его задают один раз под оборудование и не меняют от варки к варке.

Способ затирания (настой, долив, отварка) живёт в рецепте: поле TYPE шага BeerXML. Это другая ось, её Самовар берёт из файла рецепта.

# Где задаётся

Настройки → вкладка «Пиво» → «Варочный порядок».

Доступны три значения:

В настройках | Что это
All-in-one / BIAB | Одна ёмкость: затор греется в кубе
HERMS | Затор гоняется насосом через змеевик в бойлере с водой
RIMS | Затор гоняется насосом через трубчатый нагреватель; контроль по обратке

Сохранение настроек пишет порядок в профиль контроллера. На странице пива и на странице импорта BeerXML нет своего переключателя порядка.

Страница пива только показывает текущий порядок из настроек. Уже сохранённую программу она сама не переписывает: смена порядка в настройках не меняет строки, которые уже стоят в контроллере.

# Что делает каждый порядок

На строках M (засыпь солода) и P (пауза) Самовар подставляет датчик ПИД и устройство перемешивания/циркуляции.

Кипячение (B), охлаждение (C) и ферментация (F) от порядка не зависят.

## All-in-one / BIAB

Типичная кастрюля или all-in-one с корзиной: ТЭН греет затор в кубе.

ПИД по датчику куба (затор).
Мешалка в обычном прерывистом режиме ( 1^-1^2^3 : мешалка, реверс после паузы, 2 с вкл / 3 с выкл).

Нужен рабочий датчик куба. Насос для затирания не обязателен.

## HERMS

Затор в кубе, нагрев через теплообменник в отдельном бойлере с водой. Самовар держит температуру воды в бойлере, насос непрерывно гоняет затор через змеевик.

ПИД по датчику воды.
Насос непрерывно ( 2^0^65535^0 : насос, без реверса, всегда включён).
Датчик куба остаётся для контроля затора на экране, но не ведёт ПИД на паузах.

Нужны: датчик воды в бойлере, циркуляционный насос, обвязка змеевика. Каскада «вода ведёт затор вторым контуром» в прошивке нет: закон управления — обычный ПИД по выбранному датчику шага.

## RIMS

Затор в кубе, нагрев в трубке на линии циркуляции. Самовар держит температуру обратки (в прошивке это датчик царги).

ПИД по датчику царги (ставьте его на обратку после RIMS-трубки).
Насос непрерывно, как у HERMS.

На реальном RIMS нагрев без потока пережигает трубку. Самовар не глушит ТЭН сам, если насос остановился: это обязанность обвязки и оператора. Не запускайте RIMS-паузы без потока.

# Импорт BeerXML

Пиво → «Загрузить рецепт из XML».

Порядок берётся из настроек (страница импорта читает его с контроллера). Из рецепта:

температуры и времена шагов затирания;
TYPE шага: Temperature / Infusion / Decoction .

Неизвестный TYPE — ошибка, программа не собирается (молчаливой подстановки «просто пауза» нет).

Первая строка программы — M: температура засыпи из INFUSE_TEMP первого шага, иначе из его STEP_TEMP , иначе 45 °C. Устройство и датчик на M — из варочного порядка.

Дальше каждый шаг затирания даёт одну или несколько строк:

TYPE шага | Что появится в программе
Temperature (настой, пустой TYPE, «настойный») | Одна P на температуру и время шага
Infusion, первый шаг | Как Temperature: сразу P (долив засыпи — это и есть M)
Infusion, со второго шага | W (дождитесь долива) → P
Decoction | две W (отбор гущи → кипячение и возврат) → P выдержки

Строка W ничего не греет и не считает время: W;0;0;0^0^0^0;0 . Оператор делает ручную операцию и нажимает «следующая программа».

На странице импорта под таблицей пауз есть подсказки: какой порядок из настроек, что долить / отварить и сколько, если объёмы есть в XML.

Кипячение собирается как раньше: только хмель с USE Boil / First Wort, сухое охмеление в программу не попадает.

После импорта проверьте программу на вкладке «Программа» и при необходимости поправьте датчик или мешалку вручную — порядок из настроек применяется в момент сборки, а не при каждом открытии страницы пива.

Программа пива — максимум 20 строк. Отварка съедает три строки на шаг (две W и P). Длинный decoction-рецепт плюс кипячение по хмелю может не влезть: упростите шаги или объедините паузы.

# Ручная программа

Формат строки: тип;температура;время;устройство;датчик .

Датчики на шаге:

Значение | Где стоит датчик
0 | Куб (затор)
1 | Вода (бойлер HERMS)
2 | Царга / обратка RIMS
3 | Пар
4 | ТСА

Типичные строки затирания после импорта:

# All-in-one, две настойные паузы M;45;0;1^-1^2^3;0

P;65;60;1^-1^2^3;0
P;72;15;1^-1^2^3;0

# HERMS, тот же профиль пауз M;45;0;2^0^65535^0;1

P;65;60;2^0^65535^0;1
P;72;15;2^0^65535^0;1

# RIMS

M;45;0;2^0^65535^0;2
P;65;60;2^0^65535^0;2

# Infusion: вторая пауза после долива W;0;0;0^0^0^0;0

P;76;10;…;…

# Decoction: две ручные операции, затем выдержка W;0;0;0^0^0^0;0

W;0;0;0^0^0^0;0
P;70;30;…;…

На W температура и время должны быть нули. На P — температура и время больше нуля.

Смена порядка в настройках не перекладывает уже установленную программу. Чтобы перейти с all-in-one на HERMS, либо заново импортируйте рецепт, либо вручную поставьте на M/P датчик 1 и насос 2^0^65535^0 .

# Практические замечания

Сначала соберите обвязку и датчики, потом выберите порядок, потом импортируйте рецепт.
HERMS и RIMS имеют смысл только если насос реально гоняет затор через теплообменник / трубку. Иначе ПИД крутит ТЭН, а затор стоит.
Для HERMS датчик воды должен быть в бойлере, не в кубе. Для RIMS датчик царги — на обратке после нагревателя, не «где-нибудь на колонне».
All-in-one можно оставить даже на HERMS/RIMS-железе, если хотите греть только куб без циркуляции — это уже не тот порядок, ПИД не будет смотреть на бойлер/обратку. PID-коэффициенты на той же вкладке «Пиво» общие для нагрева пива; отдельных коэффициентов «для HERMS» нет.

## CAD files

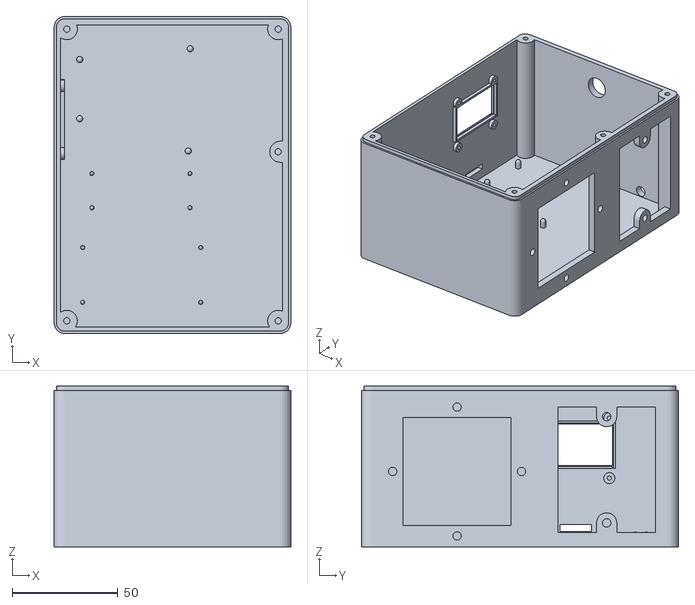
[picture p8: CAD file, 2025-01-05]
3D/SAM AVR/ SAM AVR BIG BOX.stl
112.0 x 150.0 x 76.0

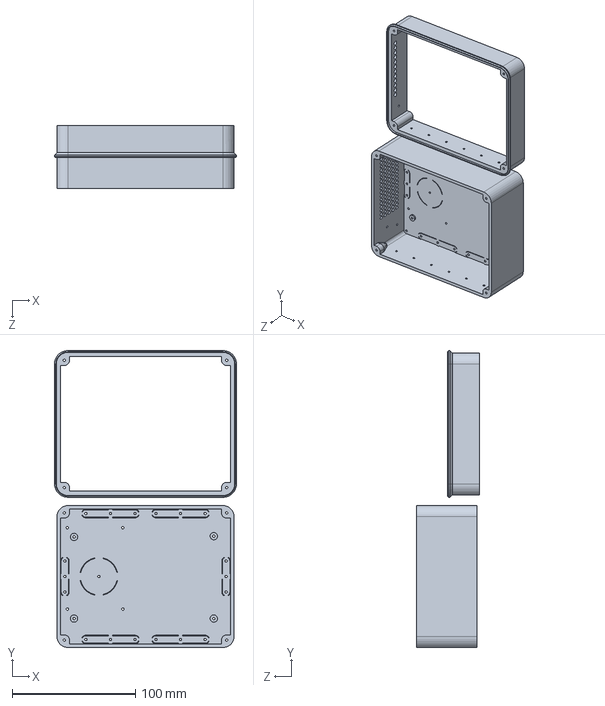
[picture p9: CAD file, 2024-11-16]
3D/Samovar Box by dranek/Body.SLDPRT
147.7 x 240.9 x 50.9 mm

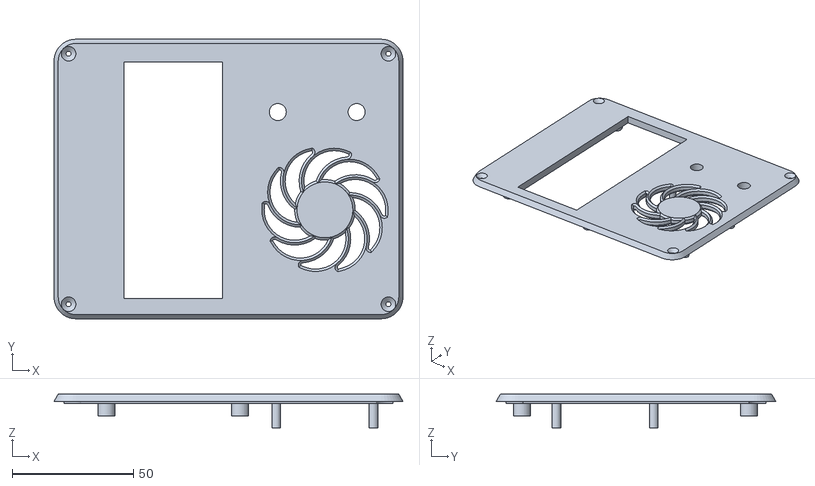
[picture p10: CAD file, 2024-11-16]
3D/Samovar Box by dranek/STL/Top.STL
143.7 x 115.2 x 14.0

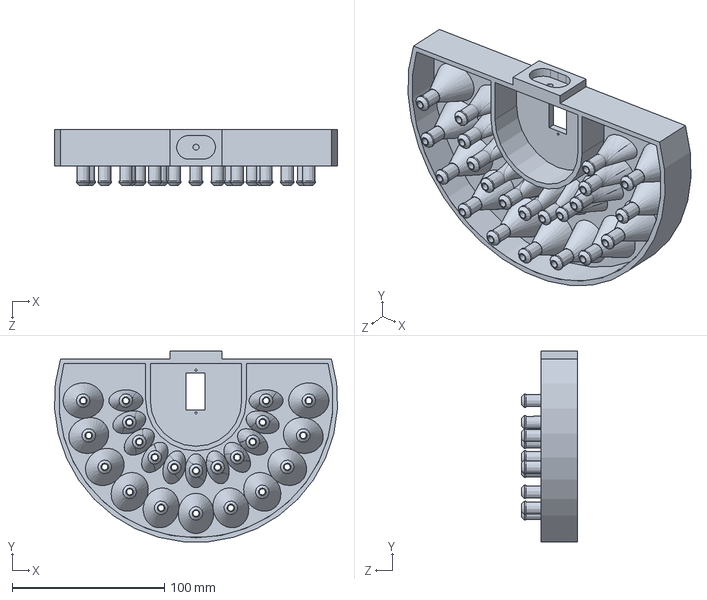
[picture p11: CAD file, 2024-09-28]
3D/Лоток7/Лоток7.SLDPRT
185.7 x 125.0 x 37.0 mm

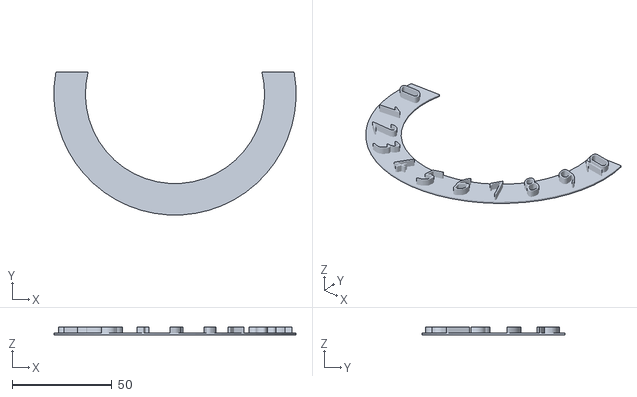
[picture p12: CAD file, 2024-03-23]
3D/Нумерация узла разбора.stl
121.6 x 71.7 x 3.80

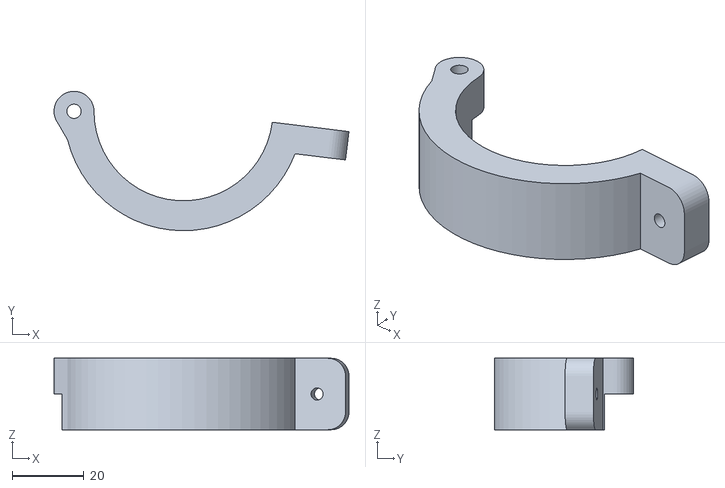
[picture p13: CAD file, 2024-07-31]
3D/Узел разбора на 22 емкости/Зажим.STL
82.4 x 39.0 x 20.0

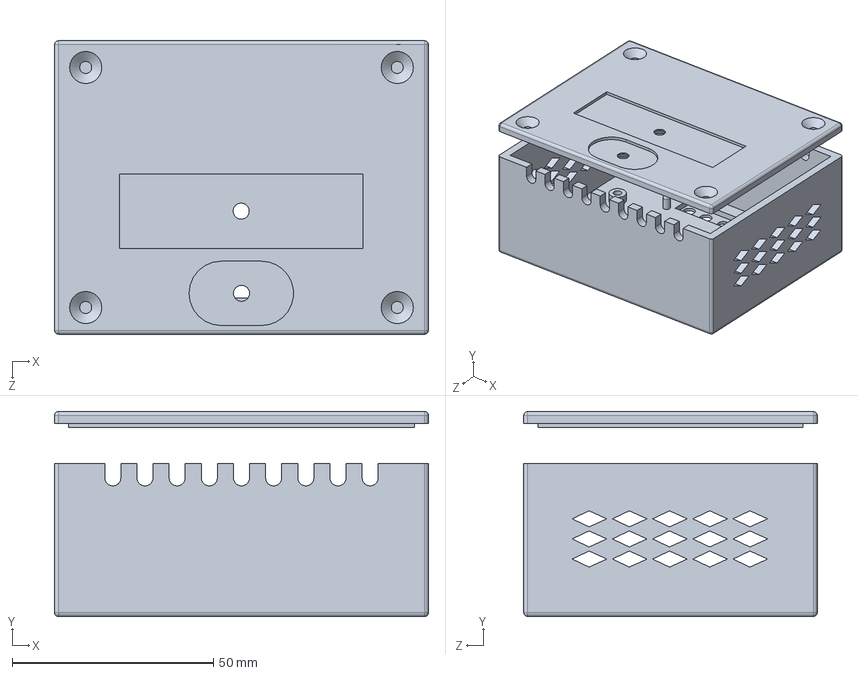
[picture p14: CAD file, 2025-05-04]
pro_mini_ntc/Корпус/Body.SLDPRT
93.0 x 51.0 x 73.0 mm

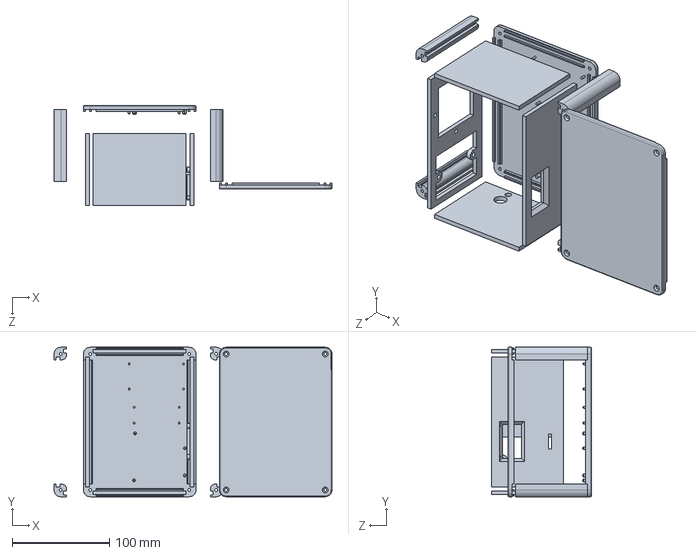
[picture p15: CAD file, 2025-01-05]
3D/SAM AVR/SAM AVR.SLDPRT
286.3 x 154.0 x 103.0 mm

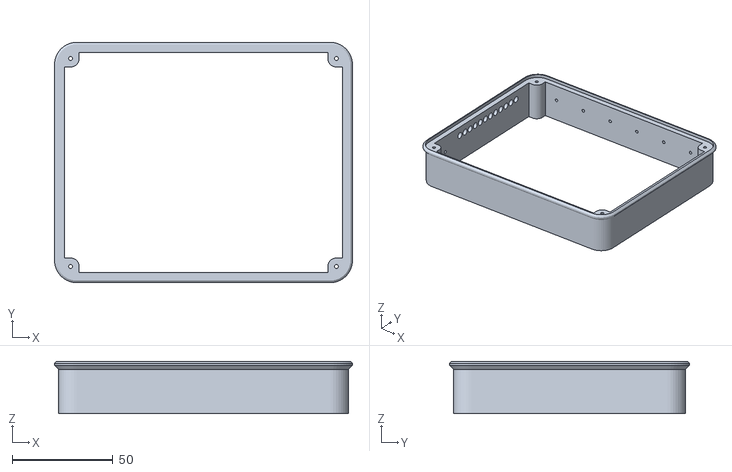
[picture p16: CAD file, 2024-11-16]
3D/Samovar Box by dranek/STL/Body2.STL
147.7 x 119.2 x 26.0

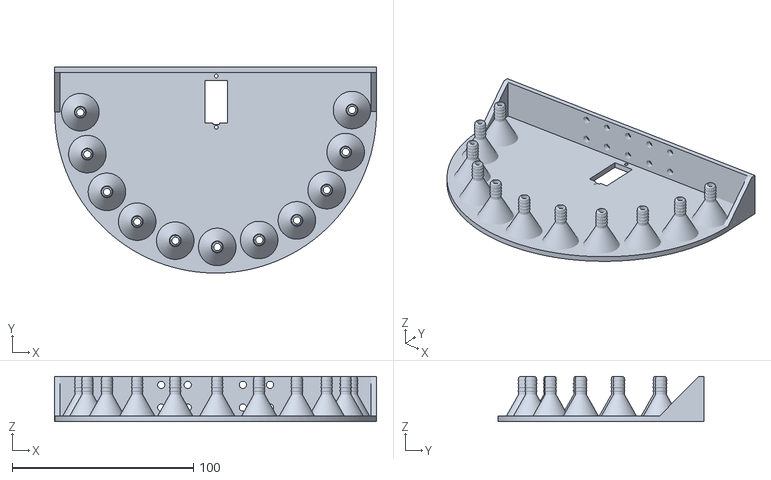
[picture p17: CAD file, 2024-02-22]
3D/Samovar_plate.stl
177.8 x 113.8 x 25.0

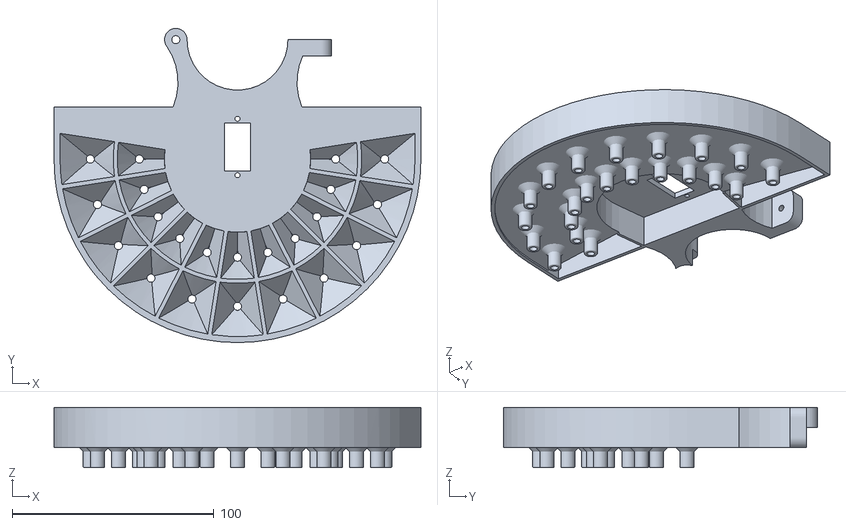
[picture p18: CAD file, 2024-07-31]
3D/Узел разбора на 22 емкости/Лоток6.STL
182.0 x 155.8 x 30.0

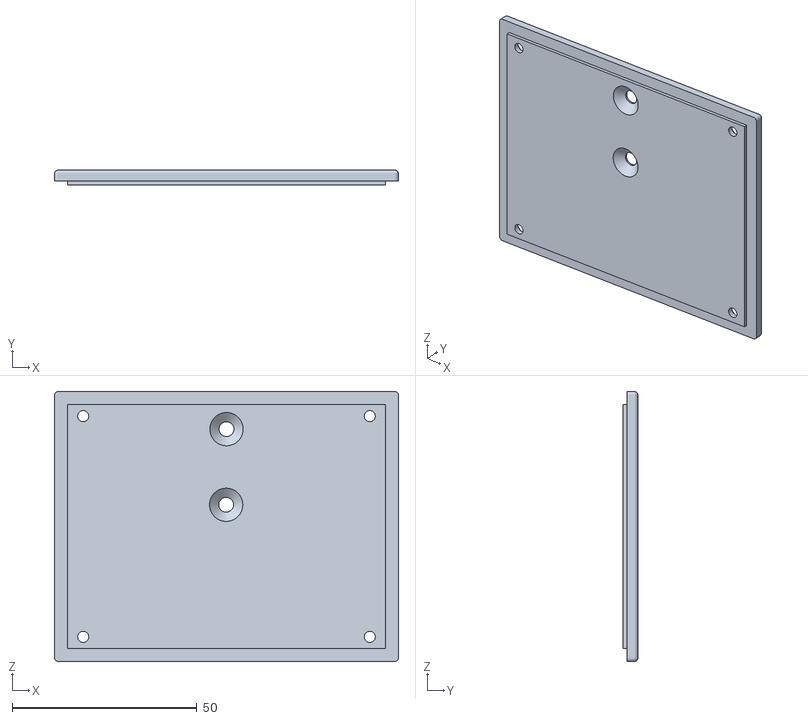
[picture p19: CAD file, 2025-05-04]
pro_mini_ntc/Корпус/Lid.STL
93.0 x 4.00 x 73.0

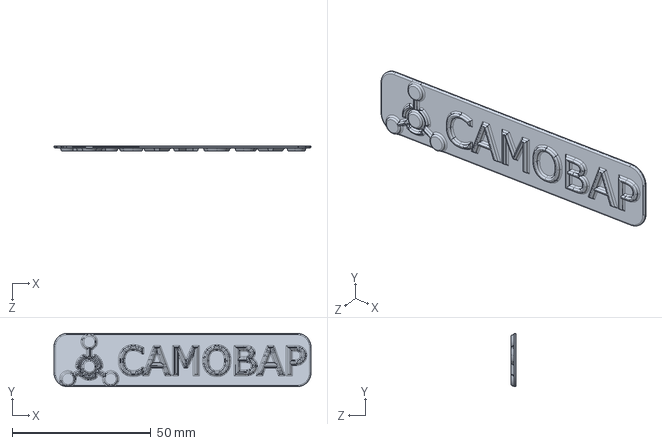
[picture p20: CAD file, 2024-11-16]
3D/Samovar Box by dranek/Logo.SLDPRT
92.7 x 19.3 x 1.80 mm

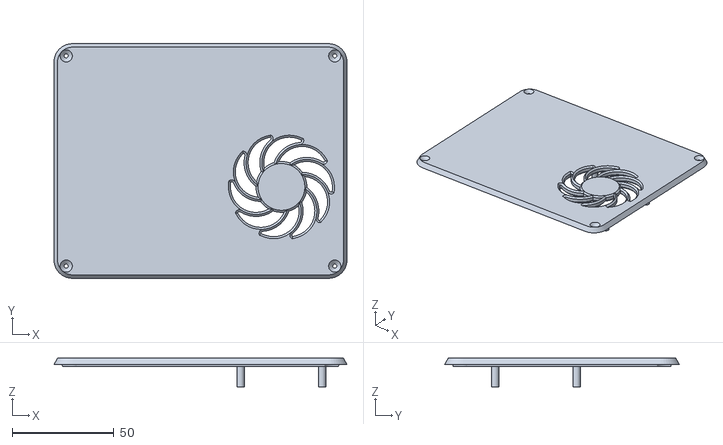
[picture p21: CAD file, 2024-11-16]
3D/Samovar Box by dranek/STL/Top_no LCD.STL
143.7 x 115.2 x 14.0

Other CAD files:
3D/Samovar Box by dranek/Сборка.SLDASM
3D/SAM AVR/ SAM AVR v22 stoyki.stl
3D/Samovar_Top.stl
3D/Узел разбора на 22 емкости/Скоба.STL
3D/SAM AVR/ SAM AVR BIG TOP.stl
3D/SAM AVR/SAM AVR BIG BOX.f3d
3D/SAM AVR/SAM AVR BOX v18.f3d
3D/SAM AVR/SAM AVR BOX.stl
3D/SAM AVR/SAM AVR TOP.stl
3D/Samovar Box by dranek/Bottom.SLDPRT
3D/Samovar Box by dranek/STL/Body.STL
3D/Samovar Box by dranek/STL/Bottom.STL
3D/Samovar Box by dranek/STL/Logo.STL
3D/Samovar Box by dranek/STL/stub.STL
3D/Samovar Box by dranek/Top_v2.SLDPRT
3D/Samovar Box by dranek/stub.SLDPRT
3D/Samovar_horn.stl
3D/horn_996_servo.stl
3D/plate_996_servo.stl
3D/ВОРОНКА САМОВАР_NEW.stl
3D/Узел разбора на 22 емкости/koromislo.STL
3D/коробка для шаговика и д.протечки.stl
pro_mini_ntc/Корпус/Body.STL

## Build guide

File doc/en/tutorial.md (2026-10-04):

# Technical Documentation: Samovar

Samovar is an automated system designed for **automating distillation, rectification, beer column (BK and NBK), beer brewing, cheese making and sous vide processes**.
It *monitors* various sensors (such as temperature and pressure),
*controls* equipment (heaters, pumps, valves) and follows predefined
*process programs* to automate tasks such as rectification or brewing beer.
Users *interact* with the system through a web interface or an LCD
(as well as through the mobile apps and the samovar-tool.ru website, connected via Blynk),
and the system includes important *safety monitoring* and *external communication* features.
Settings and programs are *saved* for persistent configuration.

## Visual Overview

```mermaid
flowchart TD
    A0["System State and Mode Management"]
    A1["Sensor Data Acquisition"]
    A2["Hardware Control (Actuators)"]
    A3["Process Program Execution"]
    A4["User Interaction (Web and LCD)"]
    A5["Configuration Persistence"]
    A6["Network and External Communication"]
    A7["Safety Monitoring and Alarms"]
    A1 -- "Reports status" --> A0
    A0 -- "Controls actuators" --> A2
    A0 -- "Manages programs" --> A3
    A0 -- "Provides status to the user interface" --> A4
    A4 -- "Sends commands from the user" --> A0
    A5 -- "Provides initial configuration" --> A0
    A1 -- "Provides sensor data to the user interface" --> A4
    A4 -- "Updates configuration" --> A5
    A6 -- "Serves the web user interface" --> A4
    A7 -- "Sends alarms externally" --> A6
    A7 -- "Triggers safety actions" --> A0
    A7 -- "Notifies the user interface about alarms" --> A4
    A3 -- "Controls actuators according to the program" --> A2
    A5 -- "Defines programs" --> A3
    A5 -- "Provides actuator settings" --> A2
    A5 -- "Provides safety settings" --> A7
    A1 -- "Informs the program logic" --> A3
    A2 -- "Reports actuator status to the user interface" --> A4
    A7 -- "Interrupts programs" --> A3
    A1 -- "Sends sensor data to the outside" --> A6
    A4 -- "Requests sensor actions" --> A1
    A5 -- "Affects user interface presentation" --> A4
    A5 -- "Provides sensor settings" --> A1
    A1 -- "Provides data for safety" --> A7
```

## Chapters

1. [User Interaction (Web and LCD)
](01_user_interaction__web___lcd__.md)
2. [Process Program Execution
](02_process_program_execution_.md)
3. [System State and Mode Management
](03_system_state___mode_management_.md)
4. [Sensor Data Acquisition
](04_sensor_data_acquisition_.md)
5. [Hardware Control (Actuators)
](05_hardware_control__actuators__.md)
6. [Safety Monitoring and Alarms
](06_safety_monitoring___alarms_.md)
7. [Configuration Persistence
](07_configuration_persistence_.md)
8. [Network and External Communication
](08_network___external_communication_.md)

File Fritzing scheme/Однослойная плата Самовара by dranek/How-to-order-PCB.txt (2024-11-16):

How to Order PCB

Please refer to:
https://docs.easyeda.com/en/PCB/Order-PCB

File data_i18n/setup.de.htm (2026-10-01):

Samovar

☾

# Einstellungen

## Einstellungen Nano I2CStepper

I2C-Geräte neu scannen

Gerät

Anschluss

Busadresse I2C

Der Platinentyp bestimmt die Adresse: ungerade — Rührwerk, gerade — Pumpe. Die neue Adresse gilt nach einem Neustart Nano.

Was die Pumpe macht

Rührwerk

Drehzahl, U/min

Lauf, s

Pause, s

Das Rührwerk läuft „Betrieb“ Sekunden, steht dann „Pause“ Sekunden und so weiter im Kreis. Betrieb 0 — es dreht ohne Halt.

Dauerförderung

Förderrate, ml/h

Volumen füllen

Volumen, ml

Rate, ml/h

Die Pumpe fördert das eingestellte Volumen und hält selbst an.

Pumpenkalibrierung

Motorschritte je 1 ml

Mit dieser Zahl wird ml/h in Motorgeschwindigkeit umgerechnet. Fördert die Pumpe mehr als eingestellt, die Zahl erhöhen, bei weniger verringern.

Pumpenkalibrierung I2CStepper

Auf der Kalibrierseite fördert die Pumpe 100 ml in einen Messbehälter, und die Schritte je 1 ml werden automatisch berechnet.

Motor

Sanftes Anfahren und Bremsen

Das Anfahren dauert etwa 10 Sekunden. Beim Lauf auf ein eingestelltes Volumen oder eine Zeit bremst der Motor ebenso sanft; Dauerdrehung stoppt sofort.

Speichern in Nano

Diese Einstellungen liegen auf der Nano-Platine selbst und werden nur mit dieser Taste geschrieben. Die Taste „Speichern“ unten auf der Seite gilt für sie nicht.

## Betriebsmodus

## Rektifikation, Destillation und MK bis zur Kesseltemperatur: °CIst „Druckkorrektur verwenden“ aus und die Zeit der Abschlusskontrolle (unten) gleich 0, kann der eingestellte Schwellwert (Standard 99.9°C) in der Höhe unerreichbar sein - der Prozess stoppt dann nicht von selbst.

Zeit für die Abschlusskontrolle des Destillationsprozesses: minZeit in Minuten zum Beenden von Destillation und MK-Betrieb, sofern sich der Kesselsensorwert nicht ändert. Höchstens 255 Minuten. 0 - nicht berücksichtigen. Standard - 60 Minuten; bei geringer Heizleistung kann der Abschluss bei noch 1-3% Alkohol im Kessel erfolgen.

## Druckkorrektur verwenden

## Rücklauf-Füllstandssensor bei der Rektifikation verwenden

## Prozessschema nicht anzeigen

## ⚙️ Geräteparameter (Kolonne)

## Durchmesser: Zoll

## Füllkörperhöhe: Meter

## Füllkörperdichte: %PackDens% % (0-100)

## Detektor für Verunreinigungsdurchbruch (Rektifikation)

## Detektor verwendenHauptschalter: ohne ihn arbeitet der Detektor gar nicht. Er beobachtet den Temperaturtrend in allen Programmzeilen (im Vorlauf nur beobachtend), setzt bei kritischem Anstieg die Abnahme auf Pause und setzt sie selbst fort

## Abnahmerate bei steigender Temperatur senkenwirkt nur zusammen mit dem Detektor: steigt der Trend über den Schwellwert, senkt der Detektor die Pumpengeschwindigkeit sanft und stellt sie wieder her, wenn sich der Trend beruhigt

## Schritt der Ratensenkung: % (0 = Standard 5, Maximum 20)

## Druck, bei dem der Notfall ausgelöst wird:Bei Erreichen dieses Drucks geht der Samovar in den NotfallmodusmmHg.

## Nullpunkt MPX:ADC-Wert bei null Überdruck. Er wird von jeder Messung abgezogen.

## MPX-Zähler je 1 mmHg.:Sensorskala: durch diese Zahl wird die Differenz zwischen dem aktuellen ADC-Wert und dem Nullpunkt geteilt. Werkswert — 12.

## Summer-Einstellungen

## Summer für Benachrichtigungen verwendenist die Option aus, ist der Summer vollständig abgeschaltet

## Summer für Benachrichtigungen im Browser verwendenist die Option aus, wird der Summer im Browser nicht verwendet

## Summer bei Programmwechsel einschaltenfür Benachrichtigung

Achtung: die Wasserzufuhr schaltet sich ein (Pumpe oder Ventil), die Schlauchpumpe der Abnahme startet, der Servoantrieb fährt 5 Behälterpositionen an.

## Adresse des Dampfsensors vor dem Dephlegmator

## Korrektur des Dampfsensors vor dem Dephlegmator: °C

## Überschreitung des Sollwerts des Dampfsensors vor dem Dephlegmator: °C

## Abnahmeverzögerung bei Überschreitung des Dampf-T-Sollwerts: s

## Adresse des Kolonnensensors

## Korrektur des Kolonnensensors bei 2/3 der Kolonne: °C

## Überschreitung des Sollwerts des Kolonnensensors bei 2/3 der Kolonne: °C

## Abnahmeverzögerung bei Überschreitung des Kolonnen-T-Sollwerts: s

## Adresse des Wassersensors

## Korrektur des Wassersensors: °C

## Sollwert des Wassersensors:In den Brennmodi — die Temperatur, die die Kühlung hält. In den Modi Bier und Käse ist dieselbe Zahl die Toleranz um die eingestellte Zeilentemperatur: von 0,3 bis 3°C. °C

## Ansprechverzögerung bei Überschreitung des Wasser-T-Sollwerts: s

## Adresse des Kesselsensors

## Korrektur des Kesselsensors: °C

## Überschreitung des Sollwerts des Kesselsensors: °C

## Ansprechverzögerung bei Überschreitung des Kessel-T-Sollwerts: s

## Adresse des ADR-Sensors

## Korrektur des ADR-Sensors °C

## Sollwert des ADR-Sensors:In den Brennmodi — die Temperatur, die die Kühlung hält. In den Modi Bier und Käse ist dieselbe Zahl die Toleranz um die eingestellte Zeilentemperatur: von 0,3 bis 3°C. °C

## Ansprechverzögerung bei Überschreitung des ADR-T-Sollwerts: s

## Anzahl der Schritte des Schrittmotors: /ml.

## I2C-Pumpe über PC verwendenDie Pumpe nimmt an der Rektifikation nur teil, wenn sie beim Start des Samovar erkannt wurde. Für den Vorlauf wird sie zur Hauptpumpe, für Mittellauf und Vorfluten arbeitet sie gleichzeitig mit der lokalen Pumpe.

## Abnahmerate über PC:Konstante Geschwindigkeit der I2C-Pumpe in den Mittellauf-Zeilen B und den Vorfluten-Zeilen C. In der Vorlauf-Zeile H gilt die Geschwindigkeit der Programmzeile selbst. l/h

## BrausystemAufbau der Brauanlage, kein Rezept. All-in-one heizt die Maische im Kessel. HERMS — PID nach dem Wassersensor (Boiler) und eine Dauerpumpe. RIMS — PID nach dem Kolonnensensor (Rücklauf) und eine Dauerpumpe. Das Maischverfahren (Infusion/Dekoktion) kommt aus dem TYPE des Schritts BeerXML.

## Koeffizienten für den PID-Regler der Heizung:

## Kp:

## Ki:

## Kd:

## Reglerspannung/-leistung im Temperaturhaltemodus.: V

## Reglerspannung/-leistung im Heiz- und Kochmodus: V

## MK-Leistung nach Siedebeginn: V

## Aufheiz-Heizelement beim Kochen verwendenWird ein Aufheiz-Heizelement verwendet, kann es auch im Kochmodus genutzt werden. In der Destillation: ist dieses Kästchen aus, wird das Aufheiz-Heizelement beim Siedebeginn sofort abgeschaltet.

## Einstellungen zum Käsen:

Anschluss für den Modus «Käse»: falls definiert USE_ADS1115, der pH-Sensor wird automatisch von AIN0 des ADS1115 unter der angegebenen Adresse gelesen, und LUA_PIN wird für pH nicht verwendet. Wird der ADS1115 nicht gefunden, sind Käsen und pH-Kalibrierung gesperrt, die übrigen Modi arbeiten weiter. Ohne USE_ADS1115 PH-4502C belegt LUA_PIN und kollidiert mit dem MPX5010DP. Das Ablassventil belegt Relais Nr. 4 anstelle des Aufheiz-Heizelements.

## KMK-Einstellungen:

## Trägheit:Zeit (s), in der die Kolonne nach einer Änderung von Leistung oder Zulauf in einen neuen stabilen Zustand kommt. Standard 180. Bei dicken Getreidemaischen und Kolonnen mit Vorwärmung meist 300-600: nach Forenerfahrung dauert die Reaktion auf einen Schritt 5-15 Minuten.

## Delta:Zulässige Abweichung der Schlempetemperatur von der Bezugs-Tn, innerhalb derer Leistung und Zulauf unverändert bleiben.

## Leistungsschritt:Um wie viele Watt die Automatik die Leistung bei einer Korrektur ändert.

## Zulaufschritt:Um wie viele Liter pro Stunde die Automatik den Maischezulauf bei einer Korrektur ändert.

## T Dampf:Obere Arbeitsgrenze der Dampftemperatur. Nähert sie sich dieser, verringert die Automatik den Zulauf.

## Flutdruck:Schwellwert des Drucksensors, bei dem Fluten festgestellt wird. Die Arbeitsobergrenze des Drucks ist die Hälfte dieses Werts (zum Beispiel bei 40 mm sind es 20 mm, wie in der HD-Anleitung): darüber senkt die Automatik den Zulauf.

## Ende-T (Schlempe):Bezugstemperatur der abgepressten Schlempe. In der ersten Iteration der Optimierung wird sie nach dem Sensorwert automatisch nach oben präzisiert (bis 102°C). °C

## Strom bei Fluten per Servoantrieb umschaltenBeim Fluten wird Position 1 gewählt — schmutziger Strom. Position 0 — sauberer Strom — kehrt erst nach einer vollen Erholungspause oder beim Ende der KMK zurück.

## Token Blynk:

## URL des Kameravideos:

## Zeitzone:

## Prüfung der Reglerverbindung verwendenWird ein Regler verwendet, schaltet der Samovar bei fehlender Verbindung zu ihm die Stromversorgung ab

## Heizelement-Widerstand für die Leistungsberechnung: Ohm

## Netzspannung: V

## Wasserdurchfluss-Kontrolle verwendenIst ein Wasserdurchfluss-Sensor angeschlossen, können seine Werte bei ausgeschalteter Option ignoriert werden

## Farben für Temperaturen:

## Dampftemperatur

## Temperatur des Sensors in der Kolonne

## Wassertemperatur

## Temperatur des Sensors im Kessel

## Temperatur des Sensors im ADR

Farben lassen sich hier auswählen (https://www.w3schools.com/colors/colors_picker.asp)

## Pegel-Einstellungen für Relais

## Relais 1

## Relais 2

## Relais 3

## Relais 4

Einstellungsdatei hochladen

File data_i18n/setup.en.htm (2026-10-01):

Samovar

☾

# Settings

## Settings Nano I2CStepper

Rescan I2C devices

Device

Connection

Address on bus I2C

The board type sets the address: odd is mixer, even is pump. The new address takes effect after rebooting Nano.

What the pump does

Mixer

Speed, rpm

Run, s

Pause, s

The mixer runs for «Run» seconds, then stops for «Pause» seconds, and so on. Run 0 — it rotates without stopping.

Continuous feed

Feed rate, ml/h

Fill volume

Volume, ml

Rate, ml/h

The pump dispenses the set volume and stops by itself.

Pump calibration

Motor steps per 1 ml

This number converts ml/h into motor speed. If the pump dispenses more than set, increase the number; if less, decrease it.

Pump calibration I2CStepper

On the calibration page the pump dispenses 100 ml into a measuring container, and the steps per 1 ml are calculated automatically.

Motor

Smooth acceleration and braking

Acceleration takes about 10 seconds. When running for a set volume or time the motor also brakes smoothly; continuous rotation stops immediately.

Save to Nano

These settings are stored in the Nano board itself and are written only by this button. The «Save» button at the bottom of the page does not apply to them.

## Operating mode

## Rectification, distillation and BC up to boiler temperature: °CIf «Use pressure correction» is off and the completion control time (below) is 0, at altitude the set threshold (default 99.9°C) may be unreachable - the process will not stop by itself.

## Time for distillation completion control: minTime in minutes to stop distillation and BC operation, provided that the boiler sensor value does not change. No more than 255 minutes. 0 - ignore. Default - 60 minutes; with low heating power it may finish with 1-3% of alcohol remaining in the boiler.

## Use pressure correction

## Use reflux level sensor during rectification

## Do not show the process diagram

## ⚙️ Equipment parameters (column)

## Diameter: inches

## Packing height: meters

## Packing density: %PackDens% % (0-100)

## Impurity breakthrough detector (rectification)

## Use detectormaster switch: without it the detector does not work at all. It watches the temperature trend on all program lines (on heads it only observes), pauses take-off on a critical rise and resumes it by itself

## Reduce take-off rate when temperature risesworks only together with the detector: when the trend rises above the threshold, the detector smoothly reduces the pump speed and restores it when the trend calms down

## Rate reduction step: % (0 = default 5, maximum 20)

## Pressure that triggers an emergency:When this pressure is reached, Samovar enters emergency modemmHg.

## Zero point MPX:ADC reading at zero gauge pressure. It is subtracted from every measurement.

## MPX counts per 1 mmHg.:Sensor scale: the difference between the current ADC reading and the zero point is divided by this number. Factory value — 12.

## Buzzer settings

## Use buzzer for notificationswhen the option is off, the buzzer is disabled completely

## Use browser buzzer for notificationswhen the option is off, the browser buzzer is not used

## Sound the buzzer on program changefor notification

Attention: water supply will turn on (pump or valve), the peristaltic take-off pump will start, the servo will move through 5 container positions.

## Vapor sensor address before the dephlegmator

## Vapor sensor correction before the dephlegmator: °C

## Vapor sensor setpoint overshoot before the dephlegmator: °C

## Take-off delay when T vapor exceeds the setpoint: s

## Column sensor address

## Column sensor correction at 2/3 of the column: °C

## Column sensor setpoint overshoot at 2/3 of the column: °C

## Take-off delay when column T exceeds the setpoint: s

## Water sensor address

## Water sensor correction: °C

## Water sensor setpoint:In distillation modes — the temperature held by cooling. In Beer and Cheese modes the same number is the tolerance around the line set temperature: from 0.3 to 3°C. °C

## Response delay when water T exceeds the setpoint: s

## Boiler sensor address

## Boiler sensor correction: °C

## Boiler sensor setpoint overshoot: °C

## Response delay when boiler T exceeds the setpoint: s

## ACP sensor address

## ACP sensor correction °C

## ACP sensor setpoint:In distillation modes — the temperature held by cooling. In Beer and Cheese modes the same number is the tolerance around the line set temperature: from 0.3 to 3°C. °C

## Response delay when ACP T exceeds the setpoint: s

## Stepper steps: /ml.

## Use I2C pump above PC (pasteurization column)The pump takes part in rectification only if it was detected at Samovar start. For heads it becomes the main pump; for body and pre-flooding it works together with the local pump.

## Take-off rate above PC:Constant I2C pump rate on body lines B and pre-flooding lines C. On heads line H the rate of the program line itself is used. l/h

## Brewing setupBrewery layout, not a recipe. All-in-one heats the mash in the boiler. HERMS — PID on the water sensor (tank) and a continuous pump. RIMS — PID on the column sensor (return) and a continuous pump. The mashing method (infusion/decoction) is taken from the step TYPE BeerXML.

## PID coefficients of the heating regulator:

## Kp:

## Ki:

## Kd:

## Regulator voltage/power in temp. hold mode.: V

## Regulator voltage/power in heating and boiling mode: V

## BC power after boiling starts: V

## Use heat-up heater during boilingIf a heat-up heater is used, it can also be used in boiling mode. In distillation: if this flag is off, the heat-up heater is switched off immediately when boiling starts.

## Cheesemaking settings:

Connection for the «Cheese»: if defined USE_ADS1115, the pH sensor is read automatically from AIN0 of the ADS1115 at the specified address, and LUA_PIN is not used for pH. If the ADS1115 is not found, cheesemaking and pH calibration are blocked, other modes keep working. Without USE_ADS1115 PH-4502C takes up LUA_PIN and conflicts with the MPX5010DP. The drain valve takes relay 4 instead of the heat-up heater.

## CBC settings:

## Inertia:Time (s) in which the column reaches a new steady state after a change of power or feed. Default 180. For thick grain mashes and columns with preheating usually 300-600: according to forum experience, the response to a step takes 5-15 minutes.

## Delta:Permissible deviation of the stillage temperature from the reference Tn within which power and feed do not change.

## Power step:By how many watts the automation changes the power per correction.

## Feed step:By how many liters per hour the automation changes the wash feed per correction.

## T vapor:Upper working limit of the vapor temperature. As it is approached, the automation reduces the feed.

## Flooding pressure:Pressure sensor threshold at which flooding is registered. The working pressure ceiling is half of this value (for example, for 40 mm it is 20 mm, as in the HD manual): above it the automation reduces the feed.

## End T (stillage):Reference temperature of pressed stillage. On the first Optimization iteration it is refined automatically upward by the sensor reading (up to 102°C). °C

## Switch the stream with the servo on floodingOn flooding, position 1 is selected — dirty stream. Position 0 — clean stream — is restored only after a full recovery pause or when CBC finishes.

## Token for Blynk:

## URL of camera video:

## Time zone:

## Use regulator connection checkIf a regulator is used, Samovar switches the power off when communication with it is lost

## Heater resistance for power calculation: Ohm

## Mains voltage: V

## Use water flow controlIf a water flow sensor is connected, with the option off its readings can be ignored

## Temperature colors:

## Vapor temperature

## Column sensor temperature

## Water temperature

## Boiler sensor temperature

## ACP sensor temperature

colors can be picked here (https://www.w3schools.com/colors/colors_picker.asp)

## Relay level settings

## Relay 1

## Relay 2

## Relay 3

## Relay 4

Upload settings file

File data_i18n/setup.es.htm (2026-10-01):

Samovar

☾

# Ajustes

## Ajustes Nano I2CStepper

Volver a buscar dispositivos I2C

Dispositivo

Conexión

Dirección en el bus I2C

El tipo de placa fija la dirección: impar es agitador, par es bomba. La nueva dirección funcionará tras reiniciar Nano.

Qué hace la bomba

Agitador

Velocidad, rpm

Trabajo, s

Pausa, s

El agitador gira «Trabajo» segundos, luego se detiene «Pausa» segundos, y así en ciclo. Trabajo 0: gira sin parar.

Caudal constante

Caudal de alimentación, ml/h

Llenado de volumen

Volumen, ml

Caudal, ml/h

La bomba dosifica el volumen indicado y se detiene sola.

Calibración de la bomba

Pasos del motor por 1 ml

Con este número los ml/h se convierten en velocidad del motor. Si la bomba dosifica más de lo indicado, aumente el número; si menos, redúzcalo.

Calibración de la bomba I2CStepper

En la página de calibración la bomba dosifica 100 ml en un recipiente graduado y los pasos por 1 ml se calculan solos.

Motor

Aceleración y frenado suaves

La aceleración dura unos 10 segundos. Al trabajar por volumen o tiempo indicados el motor también frena suavemente; la rotación continua se detiene de inmediato.

Guardar en Nano

Estos ajustes se guardan en la propia placa Nano y se escriben solo con este botón. El botón «Guardar» al final de la página no se aplica a ellos.

## Modo de trabajo

## Rectificación, destilación y CM hasta la temperatura del calderín: °CSi «Usar corrección de presión» está desactivada y el tiempo de control de finalización (abajo) es 0, en altitud el umbral fijado (por defecto 99.9°C) puede ser inalcanzable: el proceso no se detendrá solo.

Tiempo para el control de finalización del proceso de destilación: minTiempo en minutos para detener la destilación y el trabajo del CM, siempre que el valor del sensor del calderín no cambie. No más de 255 minutos. 0: no tener en cuenta. Por defecto: 60 minutos; con poca potencia de calentamiento puede terminar con un 1-3% de alcohol restante en el calderín.

## Usar corrección de presión

## Usar el sensor de nivel de flema en la rectificación

## No mostrar el esquema del proceso

## ⚙️ Parámetros del equipo (columna)

## Diámetro: pulgadas

## Altura del relleno: metros

## Densidad del relleno: %PackDens% % (0-100)

## Detector de fuga de impurezas (rectificación)

## Usar detectorinterruptor general: sin él el detector no funciona en absoluto. Vigila la tendencia de temperatura en todas las líneas del programa (en cabezas solo observa), ante una subida crítica pone la extracción en pausa y la reanuda por sí mismo

## Reducir el caudal de extracción al subir la temperaturaactúa solo junto con el detector: cuando la tendencia supera el umbral, el detector reduce suavemente la velocidad de la bomba y la devuelve cuando la tendencia se calma

## Paso de reducción de velocidad: % (0 = por defecto 5, máximo 20)

## Presión a la que se activa la emergencia:Al alcanzar esta presión el Samovar pasará al modo de emergenciammHg.

## Punto cero MPX:Lectura del ADC con presión relativa cero. Se resta de cada medición.

## Cuentas MPX por 1 mmHg.:Escala del sensor: la diferencia entre la lectura actual del ADC y el punto cero se divide por este número. Valor de fábrica — 12.

## Ajustes del zumbador

## Usar el zumbador para notificacionescon el parámetro desactivado el zumbador se apaga por completo

## Usar el zumbador del navegador para notificacionescon el parámetro desactivado no se usa el zumbador del navegador

## Activar el zumbador al cambiar de programapara notificación

Atención: se activará el suministro de agua (bomba o válvula), se pondrá en marcha la bomba peristáltica de extracción, el servo recorrerá las 5 posiciones de los recipientes.

## Dirección del sensor de vapor antes del deflegmador

## Corrección del sensor de vapor antes del deflegmador: °C

## Desviación de la consigna del sensor de vapor antes del deflegmador: °C

## Retardo de la extracción cuando la T del vapor supera la consigna: s

## Dirección del sensor de la columna

## Corrección del sensor de la columna a 2/3 de la columna: °C

## Desviación de la consigna del sensor de la columna a 2/3 de la columna: °C

## Retardo de la extracción cuando la T de la columna supera la consigna: s

## Dirección del sensor de agua

## Corrección del sensor de agua: °C

## Consigna del sensor de agua:En los modos de destilación, la temperatura que mantiene la refrigeración. En los modos Cerveza y Queso este mismo número es la tolerancia en torno a la temperatura fijada de la línea: de 0,3 a 3°C. °C

## Retardo de actuación cuando la T del agua supera la consigna: s

## Dirección del sensor del calderín

## Corrección del sensor del calderín: °C

## Desviación de la consigna del sensor del calderín: °C

## Retardo de actuación cuando la T del calderín supera la consigna: s

## Dirección del sensor de la TCA

## Corrección del sensor de la TCA °C

## Consigna del sensor de la TCA:En los modos de destilación, la temperatura que mantiene la refrigeración. En los modos Cerveza y Queso este mismo número es la tolerancia en torno a la temperatura fijada de la línea: de 0,3 a 3°C. °C

## Retardo de actuación cuando la T de la TCA supera la consigna: s

## Número de pasos del motor paso a paso: /ml.

## Usar bomba I2C sobre PCLa bomba participa en la rectificación solo si se detectó al iniciar el Samovar. Para las cabezas pasa a ser la bomba principal; para el corazón y la preinundación trabaja a la vez que la bomba local.

## Caudal de extracción sobre PC:Velocidad constante de la bomba I2C en las líneas de corazón B y de preinundación C. En la línea de cabezas H se toma la velocidad de la propia línea del programa. l/h

Esquema de elaboraciónEsquema de la cervecería, no una receta. All-in-one calienta el macerado en el calderín. HERMS: PID por el sensor de agua (caldera) y bomba continua. RIMS: PID por el sensor de la columna (retorno) y bomba continua. El método de maceración (infusión/decocción) se toma del TYPE del paso BeerXML.

## Coeficientes del PID del regulador de calentamiento:

## Kp:

## Ki:

## Kd:

## Tens./potencia del regulador en modo de mantenimiento de temp.: V

## Tens./potencia del regulador en modo de calentamiento y hervido: V

## Potencia del CM tras empezar a hervir: V

## Usar la resistencia de aceleración durante el hervidoSi se usa una resistencia de aceleración, se puede usar también en el modo de hervido. En destilación: si esta casilla está desactivada, la resistencia de aceleración se apaga al instante al empezar a hervir.

## Ajustes de elaboración de queso:

Conexión para el modo «Queso»»: si está definido USE_ADS1115, el sensor de pH se lee automáticamente de AIN0 del ADS1115 en la dirección indicada, y LUA_PIN no se usa para el pH. Si no se encuentra el ADS1115, la elaboración de queso y la calibración de pH quedan bloqueadas, los demás modos siguen funcionando. Sin USE_ADS1115 PH-4502C ocupa LUA_PIN y entra en conflicto con el MPX5010DP. La válvula de vaciado ocupa el relé 4 en lugar de la resistencia de aceleración.

## Ajustes del CMC:

## Inercia:Tiempo (s) en que la columna alcanza un nuevo estado estable tras un cambio de potencia o de alimentación. Por defecto 180. Para mostos de grano espesos y columnas con precalentamiento suele ser 300-600: según la experiencia de los foros, la respuesta a un escalón tarda 5-15 minutos.

## Delta:Desviación admisible de la temperatura de la vinaza respecto a la Tn de referencia, dentro de la cual no cambian la potencia ni la alimentación.

## Paso de potencia:Cuántos vatios cambia el automatismo la potencia en cada corrección.

## Paso de alimentación:Cuántos litros por hora cambia el automatismo la alimentación de mosto en cada corrección.

## T vapor:Límite de trabajo superior de la temperatura del vapor. Al acercarse a él el automatismo reduce la alimentación.

## Presión de inundación:Umbral del sensor de presión al que se registra la inundación. El techo de presión de trabajo es la mitad de este valor (por ejemplo, para 40 mm son 20 mm, como en el manual de HD): por encima el automatismo reduce la alimentación.

## T de finalización (vinaza):Temperatura de referencia de la vinaza prensada. En la primera iteración de Optimización se afina automáticamente al alza según la lectura del sensor (hasta 102°C). °C

## Conmutar el flujo con el servo en caso de inundaciónEn caso de inundación se elige la posición 1: flujo sucio. La posición 0, flujo limpio, se restablece solo tras una pausa de recuperación completa o al terminar el CMC.

## Token Blynk:

## URL del vídeo de la cámara:

## Zona horaria:

## Usar la comprobación de conexión del reguladorSi se usa un regulador, al perder la comunicación con él el Samovar apaga la alimentación

## Resistencia de la resistencia para el cálculo de potencia: Ohm

## Tensión de red: V

## Usar control de caudal de aguaSi hay un sensor de caudal de agua conectado, con la opción desactivada se pueden ignorar sus lecturas

## Colores de temperaturas:

## Temperatura del vapor

## Temperatura del sensor en la columna

## Temperatura del agua

## Temperatura del sensor en el calderín

## Temperatura del sensor en la TCA

los colores se pueden elegir aquí (https://www.w3schools.com/colors/colors_picker.asp)

## Ajustes de niveles de los relés

## Relé 1

## Relé 2

## Relé 3

## Relé 4

Cargar archivo de ajustes

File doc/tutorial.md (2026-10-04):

# Техническая документация: Самовар

Самовар -- это автоматизированная система, предназначенная для **автоматизации процессов дистилляции, ректификации, работы бражной колонны (БК и НБК), пивоварения, сыроварения и сувида**.
Она *контролирует* различные датчики (такие как температура и давление),
*управляет* оборудованием (нагреватели, насосы, клапаны) и следует заранее заданным
*программам процессов* для автоматизации таких задач, как ректификация или варка пива.
Пользователи *взаимодействуют* с системой через веб-интерфейс или ЖК-экран
(а также через мобильные приложения и сайт samovar-tool.ru, связь с которыми идёт через Blynk),
а система включает в себя важные функции *мониторинга безопасности* и *внешней связи*.
Настройки и программы *сохраняются* для постоянной конфигурации.

## Визуальный обзор

```mermaid
flowchart TD
    A0["Управление состоянием и режимом системы"]
    A1["Сбор данных с датчиков"]
    A2["Управление оборудованием (приводы)"]
    A3["Выполнение программ процесса"]
    A4["Взаимодействие с пользователем (веб и ЖК)"]
    A5["Сохранение конфигурации"]
    A6["Сеть и внешняя связь"]
    A7["Мониторинг безопасности и сигналы тревоги"]
    A1 -- "Сообщает о состоянии" --> A0
    A0 -- "Управляет исполнительными механизмами" --> A2
    A0 -- "Управляет программами" --> A3
    A0 -- "Предоставляет статус пользовательскому интерфейсу" --> A4
    A4 -- "Отправляет команды от пользователя" --> A0
    A5 -- "Предоставляет начальную конфигурацию" --> A0
    A1 -- "Предоставляет данные датчиков пользовательскому интерфейсу" --> A4
    A4 -- "Обновляет конфигурацию" --> A5
    A6 -- "Обслуживает веб-пользовательский интерфейс" --> A4
    A7 -- "Отправляет сигналы тревоги внешне" --> A6
    A7 -- "Запускает действия по обеспечению безопасности" --> A0
    A7 -- "Уведомляет пользовательский интерфейс о сигналах тревоги" --> A4
    A3 -- "Управляет исполнительными механизмами в соответствии с программой" --> A2
    A5 -- "Определяет программы" --> A3
    A5 -- "Предоставляет настройки исполнительных механизмов" --> A2
    A5 -- "Предоставляет настройки безопасности" --> A7
    A1 -- "Информирует программную логику" --> A3
    A2 -- "Сообщает о состоянии исполнительных механизмов интерфейсу пользователя" --> A4
    A7 -- "Прерывает программы" --> A3
    A1 -- "Отправляет данные датчиков во внешнюю среду" --> A6
    A4 -- "Запрашивает действия датчиков" --> A1
    A5 -- "Влияет на представление пользовательского интерфейса" --> A4
    A5 -- "Обеспечивает настройки датчиков" --> A1
    A1 -- "Предоставляет данные для обеспечения безопасности" --> A7
```

## Главы

1. [Взаимодействие с пользователем (веб и ЖК-дисплей)
](01_user_interaction__web___lcd__.md)
2. [Выполнение программы процесса
](02_process_program_execution_.md)
3. [Управление состоянием и режимом системы
](03_system_state___mode_management_.md)
4. [Сбор данных датчиков
](04_sensor_data_acquisition_.md)
5. [Управление оборудованием (приводы)
](05_hardware_control__actuators__.md)
6. [Мониторинг безопасности и сигналы тревоги
](06_safety_monitoring___alarms_.md)
7. [Сохранение конфигурации
](07_configuration_persistence_.md)
8. [Сеть и внешняя связь
](08_network___external_communication_.md)

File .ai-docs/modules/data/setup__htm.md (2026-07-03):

# data/setup

Модуль предоставляет функциональность для управления и настройки процессов дистилляции и ректификации в системе "Самовар" через веб-интерфейс. Он включает в себя обработку пользовательских действий, взаимодействие с сервером, сериализацию форм, загрузку и сохранение конфигураций, а также валидацию ввода. Основное назначение — обеспечение удобного и надёжного интерфейса для настройки режимов работы, параметров температуры, насоса, НБК и других компонентов.

Ключевые структуры данных
FormData — объект, содержащий данные формы для отправки на сервер
XMLHttpRequest — объект для выполнения HTTP-запросов к серверу устройства

void openTab(evt, tabName)
Активирует вкладку с указанным именем и скрывает остальные
Аргументы
evt — событие, вызвавшее переключение вкладки
tabName — имя вкладки для отображения
Возвращает
Нет
Исключения
Нет

---
void sendbutton(command)
Отправляет GET-запрос на сервер с указанным командным параметром
Аргументы
command — строка с командой, добавляемой к URL `/command?`
Возвращает
Нет
Исключения
Нет

---
int set_program()
Отправляет данные формы на сервер по адресу `/program` методом POST
Аргументы
Нет
Возвращает
0
Исключения
Показывает alert в случае ошибки HTTP-запроса

---
string HTMLElement.prototype.serialize()
Сериализует элемент формы в JSON-строку, включая текстовые поля, чекбоксы, цвета, слайдеры и select
Аргументы
Нет
Возвращает
JSON-строка с именами и значениями полей формы
Исключения
Нет

---
void loadFile(e)
Читает файл в формате JSON и передаёт данные для заполнения формы
Аргументы
e — объект File, представляющий загружаемый файл
Возвращает
Нет
Исключения
Нет

---
void mapJson(data)
Заполняет поля формы значениями из JSON-объекта
Аргументы
data — объект JSON с параметрами для установки в поля формы
Возвращает
Нет
Исключения
Нет

---
void SaveFormToFile(form)
Сохраняет данные формы в локальный файл в формате текста
Аргументы
form — элемент формы, данные которой нужно сохранить
Возвращает
Нет
Исключения
Нет

---
void sleep(milliseconds)
Выполняет блокирующую задержку выполнения кода на указанное количество миллисекунд
Аргументы
milliseconds — количество миллисекунд для задержки
Возвращает
Ничего
Исключения
Нет

---
Модуль отвечает за конфигурацию параметров оборудования и настройки температурных датчиков в системе управления ректификационной установкой. Предоставляет интерфейс для выбора физических характеристик колонны, управления аварийными срабатываниями, настройки уведомлений и калибровки датчиков. Включает элементы управления через HTML-формы с динамической подстановкой значений (шаблонизация).

Ключевые структуры данных
ColDiam — Диаметр колонны в дюймах (1.5, 2.0, 3.0)
ColHeight — Высота насадки колонны в метрах (от 0.50 до 2.50)
PackDens — Плотность упаковки насадки в процентах (60–100%)

float ColDiam(value)
Выбор диаметра ректификационной колонны
Аргументы
value — Значение диаметра в дюймах (1.5, 2.0, 3.0)
Возвращает
Выбранное значение диаметра колонны
Исключения
Нет

---
float ColHeight(value)
Выбор высоты насадки ректификационной колонны
Аргументы
value — Значение высоты в метрах (от 0.50 до 2.50 с шагом 0.25)
Возвращает
Выбранное значение высоты насадки
Исключения
Нет

---
int PackDens(value)
Установка плотности упаковки насадки
Аргументы
value — Процент плотности упаковки (60–100%)
Возвращает
Текущее значение плотности насадки
Исключения
Нет

---
bool useautospeed(checked)
Включение корректировки скорости насоса при превышении температуры пара
Аргументы
checked — Флаг включения (true/false)
Возвращает
Состояние чекбокса (включено/выключено)
Исключения
Нет

---
bool useDetectorOnHeads(checked)
Использование детектора на головах при ректификации
Аргументы
checked — Флаг активации детектора
Возвращает
Состояние использования детектора
Исключения
Нет

---
float MaxPressureValue(value)
Установка порога давления для аварийного режима
Аргументы
value — Значение давления в мм рт. ст.
Возвращает
Пороговое значение давления, при котором сработает авария
Исключения
Нет

---
bool UseBuzzer(checked)
Включение зуммера для системных уведомлений
Аргументы
checked — Флаг включения физического зуммера
Возвращает
Состояние использования зуммера
Исключения
Нет

---
bool UseBBuzzer(checked)
Включение зуммера в браузере
Аргументы
checked — Флаг включения звуковых уведомлений в веб-интерфейсе
Возвращает
Состояние использования браузерного зуммера
Исключения
Нет

---
bool ChangeProgramBuzzer(checked)
Включение зуммера при смене программы
Аргументы
checked — Флаг активации звукового оповещения
Возвращает
Состояние оповещения при смене программы
Исключения
Нет

---
void selftest(onclick)
Запуск процедуры самотестирования оборудования
Аргументы
onclick — Событие клика, вызывает sendbutton("startst")
Возвращает
Запускает тест насоса, клапана, перистальтического насоса и сервопривода
Исключения
Нет

---
string SteamAddr(value)
Выбор адреса датчика температуры пара перед дефлегматором
Аргументы
value — Адрес датчика (подставляется через шаблон %SteamAddr%)
Возвращает
Выбранный адрес датчика температуры
Исключения
Нет

---
float DeltaSteamTemp(value)
Корректировка показаний датчика температуры пара
Аргументы
value — Значение коррекции в °C
Возвращает
Скорректированное значение температуры
Исключения
Нет

---
float SetSteamTemp(value)
Уставка срабатывания по температуре пара
Аргументы
value — Пороговое значение температуры в °C
Возвращает
Температурную уставку для срабатывания
Исключения
Нет

---
int SteamDelay(value)
Задержка отбора при превышении температуры пара
Аргументы
value — Время задержки в секундах
Возвращает
Время задержки перед возобновлением отбора
Исключения
Нет

---
Модуль отвечает за конфигурацию и управление параметрами температурных датчиков, насосов и PID-регулятора в системе контроля брожения и нагрева. Предоставляет интерфейс для настройки уставок, коррекций температуры, задержек срабатывания и калибровки оборудования. Поддерживает взаимодействие с датчиками по адресам, настройку шаговых двигателей и параметров нагрева в зависимости от режима.

Ключевые структуры данных
SensorConfig — Хранит параметры датчика: адрес, коррекцию, уставку и задержку срабатывания
PumpCalibration — Определяет калибровочные коэффициенты насоса (шаги на миллилитр)
PIDSettings — Содержит коэффициенты Kp, Ki, Kd и напряжения для режимов поддержания и кипения

void saveConfig()
Сохраняет текущие настройки в энергонезависимую память устройства
Аргументы
Нет
Возвращает
Нет
Исключения
Нет

---
void loadConfig()
Загружает сохранённые настройки из энергонезависимой памяти
Аргументы
Нет
Возвращает
Нет
Исключения
Нет

---
void scanSensors()
Инициирует сканирование шины (например, One-Wire) для обнаружения подключённых датчиков температуры
Аргументы
Нет
Возвращает
Нет
Исключения
Нет

---
float readTemperature(uint8_t address)
Считывает текущее значение температуры с датчика по заданному адресу
Аргументы
address — Адрес датчика на шине
Возвращает
Текущая температура в градусах Цельсия
Исключения
Нет

---
class SensorConfig
Хранит конфигурацию одного температурного датчика
Поля
address — Адрес датчика в сети (например, One-Wire)
delta — Корректировка показаний датчика, °C
setpoint — Уставка срабатывания, °C
delay — Задержка срабатывания, сек

---
class PumpCalibration
Определяет калибровочные параметры дозирующего насоса
Поля
stepsPerMl — Количество шагов двигателя, соответствующее одному миллилитру
stepsPerMlI2C — Количество шагов I2C-насоса на миллилитр (если используется)

---
class PIDSettings
Хранит параметры PID-регулятора и выходной мощности
Поля
Kp — Пропорциональный коэффициент
Ki — Интегральный коэффициент
Kd — Дифференциальный коэффициент
stbVoltage — Напряжение в режиме поддержания температуры
boilVoltage — Напряжение в режиме кипения
useBoostElement — Флаг использования дополнительного ТЭНа при кипении

---
Модуль отвечает за веб-интерфейс конфигурации устройства "Самовар", предоставляя пользователю формы для настройки параметров работы, подключения к внешним сервисам, управления реле и восстановления/сохранения конфигурации. Интерфейс разделён на вкладки, каждая из которых отвечает за определённую группу параметров. Данные передаются и подставляются в шаблон через теги вида `%KEY%`, обрабатываемые на стороне сервера.

Ключевые структуры данных
ConfigData — Структура, содержащая все параметры конфигурации устройства, такие как токены, настройки датчиков, реле и интервалы логирования.

void saveform(this)
Сохраняет текущие настройки формы в файл конфигурации на устройстве
Аргументы
this — ссылка на элемент кнопки, вызывающий функцию
Возвращает
void
Исключения
Нет

---
void resetwifi()
Сбрасывает настройки Wi-Fi на устройстве, возвращая к заводским по умолчанию
Аргументы
Нет
Возвращает
void
Исключения
Нет

---
void reboot()
Инициирует перезагрузку устройства "Самовар"
Аргументы
Нет
Возвращает
void
Исключения
Нет

---
void loadFile(file)
Загружает и обрабатывает файл конфигурации, выбранный пользователем
Аргументы
file — объект File, выбранный через input[type="file"]
Возвращает
void
Исключения
Может выбросить ошибку при чтении файла или при неверном формате

---
void sendbutton(command)
Отправляет команду на сервер устройства через HTTP-запрос
Аргументы
command — строка с командой (например, "reboot" или "resetwifi=1")
Возвращает
void
Исключения
Может выбросить исключение при ошибке сети или недоступности сервера

---
void SaveFormToFile(button)
Сохраняет данные всех полей формы в конфигурационный файл, отправляя их на сервер
Аргументы
button — ссылка на элемент кнопки, инициирующий сохранение
Возвращает
void
Исключения
Может выбросить исключение при ошибках отправки данных

---
class tooltip
Обеспечивает отображение всплывающей подсказки при наведении на элемент
Поля
tooltiptext — текст подсказки, отображаемый внутри span с классом "tooltiptext"

---
Модуль предоставляет веб-интерфейс для сохранения данных и навигации между страницами. Основные элементы — кнопки действий, реализованные как элементы формы и кнопки с JavaScript-обработчиками. Интерфейс предназначен для простого взаимодействия пользователя с системой через стандартные действия: сохранение, возврат на главную страницу и переход в редактор.

Ключевые структуры данных
HTMLElement — Элементы управления интерфейсом, такие как кнопки формы и навигации

void <input id='save' type='submit' name='save' value='Сохранить' class="button">
Отправляет форму для сохранения данных
Аргументы
id — Уникальный идентификатор элемента
name — Имя поля формы, передаваемое при отправке
value — Отображаемый текст кнопки
class — CSS-класс для стилизации
Возвращает
Данные формы, отправленные на сервер
Исключения
Нет

---
void <input id='return' type='button' name='return' value='На главную' onclick='javascript:location.href="index.htm"' class="button">
Переходит на главную страницу
Аргументы
id — Уникальный идентификатор элемента
name — Имя кнопки
value — Отображаемый текст кнопки
onclick — Обработчик события, выполняющий переход по URL
class — CSS-класс для стилизации
Возвращает
Нет
Исключения
Нет

---
void <input id='edit' type='button' name='edit' value='Редактор' onclick='javascript:location.href="/edit"' class="button">
Переходит в редактор конфигурации
Аргументы
id — Уникальный идентификатор элемента
name — Имя кнопки
value — Отображаемый текст кнопки
onclick — Обработчик события, выполняющий переход на страницу редактирования
class — CSS-класс для стилизации
Возвращает
Нет
Исключения
Нет

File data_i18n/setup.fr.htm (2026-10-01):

Samovar

☾

# Paramètres

## Paramètres Nano I2CStepper

Rescanner les appareils I2C

Appareil

Connexion

Adresse sur le bus I2C

Le type de carte définit l’adresse : impaire pour l’agitateur, paire pour la pompe. La nouvelle adresse prendra effet après redémarrage Nano.

Rôle de la pompe

Agitateur

Vitesse, tr/min

Marche, s

Pause, s

L’agitateur tourne «Marche» secondes, puis s’arrête «Pause» secondes, et ainsi de suite. Marche 0 — il tourne sans arrêt.

Alimentation continue

Débit d’alimentation, ml/h

Remplissage d’un volume

Volume, ml

Débit, ml/h

La pompe verse le volume réglé et s’arrête d’elle-même.

Étalonnage de la pompe

Pas du moteur pour 1 ml

Avec ce nombre, les ml/h sont convertis en vitesse du moteur. Si la pompe verse plus que réglé, augmentez le nombre ; si moins, diminuez-le.

Étalonnage de la pompe I2CStepper

Sur la page d’étalonnage, la pompe verse 100 ml dans un récipient gradué et le nombre de pas pour 1 ml est calculé automatiquement.

Moteur

Accélération et freinage progressifs

Accélération d’environ 10 secondes. En marche pour un volume ou une durée donnés, le moteur freine aussi progressivement ; la rotation continue s’arrête aussitôt.

Enregistrer dans Nano

Ces paramètres sont stockés dans la carte Nano elle-même et ne s’écrivent que par ce bouton. Le bouton «Enregistrer» en bas de la page ne les concerne pas.

## Mode de fonctionnement

## Rectification, distillation et CM jusqu’à la température du bouilleur: °CSi «Utiliser la correction de pression» est désactivé et que le temps de contrôle de fin (ci-dessous) vaut 0, en altitude le seuil réglé (99.9°C par défaut) peut être inatteignable - le processus ne s’arrêtera pas de lui-même.

Temps de contrôle de fin du processus de distillation: minTemps en minutes pour arrêter la distillation et le travail de la CM, à condition que la valeur du capteur du bouilleur ne change pas. Pas plus de 255 minutes. 0 - ne pas tenir compte. Par défaut - 60 minutes ; avec une faible puissance de chauffe, la fin peut survenir avec 1-3% d’alcool restant dans le bouilleur.

## Utiliser la correction de pression

## Utiliser le capteur de niveau de reflux pendant la rectification

## Ne pas afficher le schéma du processus

## ⚙️ Paramètres de l’équipement (colonne)

## Diamètre: pouces

## Hauteur du garnissage: mètres

## Densité du garnissage: %PackDens% % (0-100)

## Détecteur de percée d’impuretés (rectification)

## Utiliser le détecteurinterrupteur général : sans lui le détecteur ne fonctionne pas du tout. Il suit la tendance de température sur toutes les lignes du programme (sur les têtes il ne fait qu’observer), met le soutirage en pause en cas de hausse critique et le reprend de lui-même

## Réduire le débit de soutirage quand la température montefonctionne uniquement avec le détecteur : quand la tendance dépasse le seuil, le détecteur réduit progressivement la vitesse de la pompe et la rétablit quand la tendance se calme

## Pas de réduction du débit: % (0 = par défaut 5, maximum 20)

## Pression qui déclenche l’urgence:Quand cette pression est atteinte, le Samovar passe en mode d’urgencemmHg.

## Point zéro MPX:Valeur du CAN à pression relative nulle. Elle est soustraite de chaque mesure.

## Points MPX pour 1 mmHg.:Échelle du capteur : la différence entre la valeur actuelle du CAN et le point zéro est divisée par ce nombre. Valeur d’usine — 12.

## Paramètres de l’avertisseur sonore

## Utiliser l’avertisseur sonore pour les notificationssi l’option est désactivée, l’avertisseur est entièrement coupé

## Utiliser l’avertisseur du navigateur pour les notificationssi l’option est désactivée, l’avertisseur du navigateur n’est pas utilisé

## Activer l’avertisseur au changement de programmepour la notification

Attention : l’arrivée d’eau va s’activer (pompe ou vanne), la pompe péristaltique de soutirage va démarrer, le servomoteur va parcourir 5 positions de récipients.

## Adresse du capteur de vapeur avant le déflegmateur

## Correction du capteur de vapeur avant le déflegmateur: °C

## Dépassement de la consigne du capteur de vapeur avant le déflegmateur: °C

## Délai du soutirage quand T vapeur dépasse la consigne: s

## Adresse du capteur de la colonne

## Correction du capteur de la colonne aux 2/3 de la colonne: °C

## Dépassement de la consigne du capteur de la colonne aux 2/3 de la colonne: °C

## Délai du soutirage quand T colonne dépasse la consigne: s

## Adresse du capteur d’eau

## Correction du capteur d’eau: °C

## Consigne du capteur d’eau:En modes de distillation — la température maintenue par le refroidissement. En modes Bière et Fromage, ce même nombre est la tolérance autour de la température réglée de la ligne : de 0,3 à 3°C. °C

## Délai de réaction quand T eau dépasse la consigne: s

## Adresse du capteur du bouilleur

## Correction du capteur du bouilleur: °C

## Dépassement de la consigne du capteur du bouilleur: °C

## Délai de réaction quand T bouilleur dépasse la consigne: s

## Adresse du capteur de la TCA

## Correction du capteur de la TCA °C

## Consigne du capteur de la TCA:En modes de distillation — la température maintenue par le refroidissement. En modes Bière et Fromage, ce même nombre est la tolérance autour de la température réglée de la ligne : de 0,3 à 3°C. °C

## Délai de réaction quand T TCA dépasse la consigne: s

## Nombre de pas du moteur pas à pas: /ml.

## Utiliser la pompe I2C au-dessus du CPLa pompe participe à la rectification seulement si elle a été détectée au démarrage du Samovar. Pour les têtes elle devient la pompe principale ; pour le cœur et le pré-engorgement elle fonctionne en même temps que la pompe locale.

## Débit de soutirage au-dessus du CP:Débit constant de la pompe I2C sur les lignes de cœur B et de pré-engorgement C. Sur la ligne de têtes H, c’est le débit de la ligne de programme elle-même qui est utilisé. l/h

Configuration de brassageSchéma de la brasserie, et non recette. All-in-one chauffe l’empâtage dans le bouilleur. HERMS — PID sur le capteur d’eau (chauffe-eau) et pompe continue. RIMS — PID sur la colonne (retour) et pompe continue. La méthode d’empâtage (infusion/décoction) est prise dans le TYPE de l’étape BeerXML.

## Coefficients du PID du régulateur de chauffe:

## Kp:

## Ki:

## Kd:

## Tens./puiss. du régulateur en mode maintien de temp..: V

## Tens./puiss. du régulateur en mode chauffe et ébullition: V

## Puissance de la CM après le début de l’ébullition: V

## Utiliser la résistance de montée en chauffe pendant l’ébullitionSi une résistance de montée en chauffe est utilisée, elle peut aussi servir en mode ébullition. En distillation : si cette case est décochée, la résistance de montée en chauffe est coupée dès le début de l’ébullition.

## Paramètres de la fromagerie:

Connexion pour le mode «Fromage»»: si défini USE_ADS1115, le capteur de pH est lu automatiquement sur AIN0 de l’ADS1115 à l’adresse indiquée, et LUA_PIN n’est pas utilisé pour le pH. Si l’ADS1115 est introuvable, la fromagerie et l’étalonnage du pH sont bloqués, les autres modes continuent de fonctionner. Sans USE_ADS1115 PH-4502C occupe LUA_PIN et entre en conflit avec le MPX5010DP. La vanne de vidange occupe le relais 4 à la place de la résistance de montée en chauffe.

## Paramètres de la CMC:

Inertie:Temps (s) au bout duquel la colonne atteint un nouvel état stable après un changement de puissance ou d’alimentation. Par défaut 180. Pour les moûts de céréales épais et les colonnes avec préchauffage, en général 300-600 : d’après l’expérience des forums, la réponse à un échelon prend 5-15 minutes.

## Delta:Écart admissible de la température de la drêche par rapport à la Tn de référence, dans lequel la puissance et l’alimentation ne changent pas.

## Pas de puissance:De combien de watts l’automatisme modifie la puissance à chaque correction.

## Pas d’alimentation:De combien de litres par heure l’automatisme modifie l’alimentation en moût à chaque correction.

## T vapeur:Limite de travail supérieure de la température de la vapeur. À l’approche de cette limite, l’automatisme réduit l’alimentation.

## Pression d’engorgement:Seuil du capteur de pression auquel l’engorgement est enregistré. Le plafond de pression de travail est la moitié de cette valeur (par exemple, pour 40 mm c’est 20 mm, comme dans le manuel HD) : au-dessus, l’automatisme réduit l’alimentation.

## T de fin (drêche):Température de référence de la drêche pressée. À la première itération de l’Optimisation elle est affinée automatiquement vers le haut d’après le capteur (jusqu’à 102°C). °C

## Basculer le flux avec le servomoteur en cas d’engorgementEn cas d’engorgement, la position 1 est choisie — flux sale. La position 0 — flux propre — n’est rétablie qu’après une pause de récupération complète ou à la fin de la CMC.

## Jeton Blynk:

## URL de la vidéo de la caméra:

## Fuseau horaire:

## Utiliser la vérification de la connexion du régulateurSi un régulateur est utilisé, le Samovar coupe l’alimentation en cas de perte de communication avec lui

## Résistance de la résistance chauffante pour le calcul de la puissance: Ohm

## Tension du secteur: V

## Utiliser le contrôle du débit d’eauSi un capteur de débit d’eau est branché, avec l’option désactivée ses valeurs peuvent être ignorées

## Couleurs des températures:

## Température de la vapeur

## Température du capteur de la colonne

## Température de l’eau

## Température du capteur du bouilleur

## Température du capteur de la TCA

les couleurs peuvent être choisies ici (https://www.w3schools.com/colors/colors_picker.asp)

## Réglage des niveaux des relais

## Relais 1

## Relais 2

## Relais 3

## Relais 4

Charger le fichier de paramètres

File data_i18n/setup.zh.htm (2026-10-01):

Samovar

☾

# 设置

## 设置 Nano I2CStepper

重新扫描I2C设备

设备

连接

总线地址 I2C

板型决定地址：奇数为搅拌器，偶数为泵。新地址在重启后生效 Nano.

泵的作用

搅拌器

速度，rpm

运行, s

暂停, s

搅拌器运转「工作」秒，然后停止「暂停」秒，如此循环。工作 0 表示持续旋转.

持续供给

供给速度，ml/h

定量灌装

体积, ml

速度，ml/h

泵灌装设定的体积后自动停止.

泵校准

每1 ml电机步数

ml/h按此数值换算为电机速度。如果泵灌出的量多于设定值，请增大该数；如果少于设定值，请减小.

泵校准 I2CStepper

在校准页面，泵向量杯灌入100 ml，每1 ml的步数由系统自动计算.

电机

平滑加速和减速

加速约10秒。按设定体积或时间运行时，电机同样平滑减速；连续旋转则立即停止.

保存到 Nano

这些设置保存在Nano板上，只能通过此按钮写入。页面底部的「保存」按钮与它们无关.

## 工作模式

## 精馏、蒸馏和醪塔，直到釜温: °C如果「使用压力修正」已关闭，且下方的结束监控时间为0，在高海拔地区设定的阈值（默认99.9°C）可能无法达到——流程不会自行停止.

## 蒸馏结束监控时间: min在釜传感器数值不变的情况下，停止蒸馏和醪塔运行的时间，单位分钟。不超过255分钟。0表示不考虑。默认60分钟；加热功率较小时，可能在釜内还剩1-3%酒精时就结束.

## 使用压力修正

## 精馏时使用回流液位传感器

## 不显示流程示意图

## ⚙️ 设备参数(塔)

## 直径: 英寸

## 填料高度: 米

## 填料密度: %PackDens% % (0-100)

## 杂质穿透检测器(精馏)

## 使用检测器总开关：关闭时检测器完全不工作。它在程序所有行上监视温度趋势（在酒头上只观察），温度危险上升时让采出暂停，并自行恢复

## 温度上升时降低采出速度仅与检测器一起生效：趋势上升超过阈值时，检测器会平滑降低泵速，趋势平稳后再恢复

## 速度降低步长: % (0 = 默认5，最大 20)

## 触发紧急状态的压力:达到此压力时，Samovar将进入紧急模式mmHg.

## 零点 MPX:表压为零时的ADC读数。每次测量都会减去它.

## 每1 mmHg的MPX计数.:传感器比例：当前ADC读数与零点之差除以此数。出厂值 — 12.

## 蜂鸣器设置

## 使用蜂鸣器提示该选项关闭时，蜂鸣器完全禁用

## 在浏览器中使用蜂鸣器提示该选项关闭时，不使用浏览器蜂鸣器

## 程序切换时启用蜂鸣器用于提示

注意：将开启供水（泵或阀），启动采出蠕动泵，伺服将经过5个容器位置.

## 分凝器前蒸汽传感器地址

## 分凝器前蒸汽传感器修正: °C

## 分凝器前蒸汽传感器设定值超限: °C

## 蒸汽温度超出设定值时的采出延迟: s

## 塔传感器地址

## 塔2/3处传感器修正: °C

## 塔2/3处传感器设定值超限: °C

## 塔温超出设定值时的采出延迟: s

## 水传感器地址

## 水传感器修正: °C

## 水传感器设定值:在蒸馏类模式中为冷却维持的温度。在啤酒和奶酪模式中，同一个数值是围绕该行设定温度的容差：从0.3到 3°C. °C

## 水温超出设定值时的响应延迟: s

## 釜传感器地址

## 釜传感器修正: °C

## 釜传感器设定值超限: °C

## 釜温超出设定值时的响应延迟: s

## 通气管传感器地址

## 通气管传感器修正 °C

## 通气管传感器设定值:在蒸馏类模式中为冷却维持的温度。在啤酒和奶酪模式中，同一个数值是围绕该行设定温度的容差：从0.3到 3°C. °C

## 通气管温度超出设定值时的响应延迟: s

## 步进电机步数: /ml.

## 在PC上方使用I2C泵只有在Samovar启动时检测到该泵，它才参与精馏。对于酒头，它成为主泵；对于酒心和预液泛，它与本地泵同时工作.

## PC上方采出速度:酒心行B和预液泛行C上I2C泵的恒定速度。酒头行H使用程序行本身的速度. l/h

## 酿造布局这是酿造设备的布局，不是配方。All-in-one在釜中加热糖化醪。HERMS：按水传感器（水箱）PID控制，泵持续运行。RIMS：按塔传感器（回流）PID控制，泵持续运行。糖化方式（浸出/煮出）取自步骤TYPE BeerXML.

## 加热调压器的PID系数:

## Kp:

## Ki:

## Kd:

## 温度保持模式下调压器的电压/功率.: V

## 加热和煮沸模式下调压器的电压/功率: V

## 沸腾后醪塔功率: V

## 煮沸时使用加速加热器如果使用加速加热器，也可以在煮沸模式下使用。在蒸馏中：如果此选项关闭，开始沸腾时加速加热器立即关闭.

## 奶酪制作设置:

「奶酪」模式的连接»: 如果已定义 USE_ADS1115, pH传感器按指定地址自动从ADS1115的AIN0读取，并且 LUA_PIN 不用于pH。如果未找到ADS1115，奶酪制作和pH校准将被锁定，其他模式继续工作。如果没有 USE_ADS1115 PH-4502C 占用 LUA_PIN 并与MPX5010DP冲突。排放阀占用继电器4，取代加速加热器.

## 连续醪塔设置:

## 惯性:功率或进料改变后，塔达到新稳定状态所需的时间（s）。默认180。对于浓稠的谷物醪和带预热的塔，通常为300-600：据论坛经验，对一次调整的响应需要5-15分钟.

## Delta:釜残液温度相对于基准Tn的允许偏差，在此范围内功率和进料不变.

## 功率步长:自动控制每次修正时功率改变的瓦数.

## 进料步长:自动控制每次修正时醪液进料改变的升每小时数.

## 蒸汽 T:蒸汽温度的工作上限。接近该上限时，自动控制会减少进料.

## 液泛压力:压力传感器上判定为液泛的阈值。工作压力上限是该值的一半（例如40 mm时为20 mm，如HD手册）：超过它时自动控制会降低进料.

## 结束T(釜残液):压榨后釜残液的基准温度。在优化的第一次迭代中，会根据传感器读数自动向上修正（最高到 102°C). °C

## 液泛时用伺服切换流向液泛时选择位置1：脏流。位置0：净流，仅在完整恢复暂停后或连续醪塔结束时恢复.

## 令牌 Blynk:

## URL 摄像头视频:

## 时区:

## 使用调压器连接检查如果使用调压器，与其失去通信时Samovar将关闭电源

## 用于计算功率的加热器电阻: Ohm

## 电网电压: V

## 使用水流量控制如果已连接水流量传感器，关闭此选项后可忽略其读数

## 温度颜色:

## 蒸汽温度

## 塔内传感器温度

## 水温度

## 釜内传感器温度

## 通气管传感器温度

可在此处选择颜色 (https://www.w3schools.com/colors/colors_picker.asp)

## 继电器电平设置

## 继电器 1

## 继电器 2

## 继电器 3

## 继电器 4

上传设置文件

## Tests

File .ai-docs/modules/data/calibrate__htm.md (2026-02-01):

# data/calibrate

/**
 * @brief Веб-интерфейс для калибровки шагового двигателя насоса.
 *
 * Модуль предоставляет HTML-страницу с интерактивным интерфейсом для калибровки шагового двигателя дозирующего насоса.
 * Поддерживается выбор типа насоса (встроенный или внешний I2C), настройка скорости двигателя и выполнение калибровки.
 * Интерфейс взаимодействует с сервером через HTTP-запросы для запуска и завершения процесса калибровки.
 *
 * Ключевые структуры данных
 * stepperStepMlLocal — Количество шагов двигателя на 100 мл для встроенного насоса (локальное значение).
 * stepperStepMlI2C — Количество шагов двигателя на 100 мл для внешнего I2C-насоса.
 */

---
getPumpType()
Возвращает текущий тип выбранного насоса.
Аргументы
Возвращает
Тип насоса: "local" или "i2c".
Исключения

---
onPumpTypeChange()
Обновляет отображаемое значение шагов на 100 мл в зависимости от выбранного типа насоса.
Аргументы
Возвращает
Исключения

---
calibrate()
Запускает или завершает процесс калибровки шагового двигателя.
Аргументы
Возвращает
Всегда возвращает 0.
Исключения
Диалог alert при ошибке HTTP-запроса.

---
window.onload()
Инициализирует интерфейс при загрузке страницы.
Аргументы
Возвращает
Исключения

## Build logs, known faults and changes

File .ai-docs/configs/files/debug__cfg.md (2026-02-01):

# debug.cfg

Конфигурационный файл предназначен для настройки OpenOCD при отладке платы ESP32-WROVER-KIT. Он определяет интерфейс подключения JTAG, используемый адаптер, напряжение питания флеш-памяти и загружает конфигурацию целевого устройства ESP32. Файл используется при запуске OpenOCD и обеспечивает корректное взаимодействие с отладочным оборудованием.

Секции и ключи

source — включает в конфигурацию содержимое другого конфигурационного файла; используется для подключения драйвера интерфейса и конфигурации целевого чипа<br>
set ESP32_FLASH_VOLTAGE 3.3 — устанавливает напряжение питания флеш-памяти в вольтах, необходимое для корректной работы внешней флеш-памяти на плате

Важные параметры

ESP32_FLASH_VOLTAGE — задаёт уровень напряжения (в вольтах), подаваемого на флеш-память; для ESP32-WROVER-KIT обычно устанавливается в 3.3 В, что соответствует логическому уровню платы

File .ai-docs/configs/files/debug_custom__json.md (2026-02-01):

# debug_custom.json

Конфигурационный файл определяет параметры отладки для проекта на базе платформы Arduino, работающего на микроконтроллере ESP32. Он задаёт инструментарий для отладки, путь к файлу описания периферии (SVD), а также команды, выполняемые при подключении и перезапуске отладки. Файл используется, например, в средах с поддержкой OpenOCD или J-Link для настройки корректного взаимодействия с целевым устройством.

Секции и ключи

name — отображаемое имя конфигурации, связанное с целевой платформой.<br>
toolchainPrefix — префикс используемого компилятора и инструментов для кросс-компиляции, в данном случае для архитектуры Xtensa (ESP32).<br>
svdFile — путь к файлу SVD (System View Description), содержащему описание регистров и периферийных блоков микроконтроллера.<br>
request — тип запрашиваемой отладочной операции; значение "attach" означает подключение к уже запущенному устройству.<br>
postAttachCommands — список команд отладчика (например, GDB), выполняемых сразу после подключения к устройству.<br>
overrideRestartCommands — команды, которые выполняются при перезапуске сессии отладки вместо стандартных действий.

Важные параметры

postAttachCommands — используются для инициализации устройства при подключении, включая остановку после сброса и установку начальной точки останова.<br>
overrideRestartCommands — обеспечивают согласованный способ перезапуска отладки, повторяя ключевые шаги инициализации.

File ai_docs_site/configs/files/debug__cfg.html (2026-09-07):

Samovar

- Главная
- Архитектура
- Запуск
- Зависимости
- Тестирование
- Соглашения
- Глоссарий
- Конфигурация проекта
  - Обзор
  - debug.cfg
  - debug_custom.json
  - platformio.ini
- Модули
  - Обзор
  - /data
    - beer.htm
    - bk.htm
    - brewxml.htm
    - calibrate.htm
    - chart.htm
    - distiller.htm
    - edit.htm
    - index.htm
    - nbk.htm
    - program.htm
    - setup.htm
    - style.css
  - beer.h
  - BK.h
  - Blynk.ino
  - column_math.h
  - crash_handler.h
  - crash_handler.ino
  - distiller.h
  - font.h
  - FS.ino
  - I2CStepper.h
  - impurity_detector.h
  - logic.h
  - lua.h
  - Menu.ino
  - mod_rmv.ino
  - mod_rmvk.h
  - nbk.h
  - NVS_Manager.ino
  - partition_manager.py
  - pumppwm.h
  - Samovar.h
  - Samovar.ino
  - Samovar_ini.h
  - Samovar_pin.h
  - sensorinit.h
  - SPIFFSEditor.h
  - WebServer.ino
- Изменения
- Search
- Previous
- Next
- debug.cfg

# debug.cfg

Конфигурационный файл предназначен для настройки OpenOCD при отладке платы ESP32-WROVER-KIT. Он определяет интерфейс подключения JTAG, используемый адаптер, напряжение питания флеш-памяти и загружает конфигурацию целевого устройства ESP32. Файл используется при запуске OpenOCD и обеспечивает корректное взаимодействие с отладочным оборудованием.

Секции и ключи

source — включает в конфигурацию содержимое другого конфигурационного файла; используется для подключения драйвера интерфейса и конфигурации целевого чипа
set ESP32_FLASH_VOLTAGE 3.3 — устанавливает напряжение питания флеш-памяти в вольтах, необходимое для корректной работы внешней флеш-памяти на плате

Важные параметры

ESP32_FLASH_VOLTAGE — задаёт уровень напряжения (в вольтах), подаваемого на флеш-память; для ESP32-WROVER-KIT обычно устанавливается в 3.3 В, что соответствует логическому уровню платы

Documentation built with MkDocs (https://www.mkdocs.org/).

#### Search

From here you can search these documents. Enter your search terms below.

#### Keyboard Shortcuts

Keys | Action
? | Open this help
n | Next page
p | Previous page
s | Search

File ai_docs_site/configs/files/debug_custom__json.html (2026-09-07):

Samovar

- Главная
- Архитектура
- Запуск
- Зависимости
- Тестирование
- Соглашения
- Глоссарий
- Конфигурация проекта
  - Обзор
  - debug.cfg
  - debug_custom.json
  - platformio.ini
- Модули
  - Обзор
  - /data
    - beer.htm
    - bk.htm
    - brewxml.htm
    - calibrate.htm
    - chart.htm
    - distiller.htm
    - edit.htm
    - index.htm
    - nbk.htm
    - program.htm
    - setup.htm
    - style.css
  - beer.h
  - BK.h
  - Blynk.ino
  - column_math.h
  - crash_handler.h
  - crash_handler.ino
  - distiller.h
  - font.h
  - FS.ino
  - I2CStepper.h
  - impurity_detector.h
  - logic.h
  - lua.h
  - Menu.ino
  - mod_rmv.ino
  - mod_rmvk.h
  - nbk.h
  - NVS_Manager.ino
  - partition_manager.py
  - pumppwm.h
  - Samovar.h
  - Samovar.ino
  - Samovar_ini.h
  - Samovar_pin.h
  - sensorinit.h
  - SPIFFSEditor.h
  - WebServer.ino
- Изменения
- Search
- Previous
- Next
- debug_custom.json

# debug_custom.json

Конфигурационный файл определяет параметры отладки для проекта на базе платформы Arduino, работающего на микроконтроллере ESP32. Он задаёт инструментарий для отладки, путь к файлу описания периферии (SVD), а также команды, выполняемые при подключении и перезапуске отладки. Файл используется, например, в средах с поддержкой OpenOCD или J-Link для настройки корректного взаимодействия с целевым устройством.

Секции и ключи

name — отображаемое имя конфигурации, связанное с целевой платформой.
toolchainPrefix — префикс используемого компилятора и инструментов для кросс-компиляции, в данном случае для архитектуры Xtensa (ESP32).
svdFile — путь к файлу SVD (System View Description), содержащему описание регистров и периферийных блоков микроконтроллера.
request — тип запрашиваемой отладочной операции; значение "attach" означает подключение к уже запущенному устройству.
postAttachCommands — список команд отладчика (например, GDB), выполняемых сразу после подключения к устройству.
overrideRestartCommands — команды, которые выполняются при перезапуске сессии отладки вместо стандартных действий.

Важные параметры

postAttachCommands — используются для инициализации устройства при подключении, включая остановку после сброса и установку начальной точки останова.
overrideRestartCommands — обеспечивают согласованный способ перезапуска отладки, повторяя ключевые шаги инициализации.

Documentation built with MkDocs (https://www.mkdocs.org/).

#### Search

From here you can search these documents. Enter your search terms below.

#### Keyboard Shortcuts

Keys | Action
? | Open this help
n | Next page
p | Previous page
s | Search

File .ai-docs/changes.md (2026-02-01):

# Изменения с последней генерации

## Добавленные файлы

- нет
## Изменённые файлы

- нет
## Удалённые файлы

- нет
## Перегенерированные разделы

- Модули
- Конфигурация проекта

## Краткое резюме

Изменений нет.

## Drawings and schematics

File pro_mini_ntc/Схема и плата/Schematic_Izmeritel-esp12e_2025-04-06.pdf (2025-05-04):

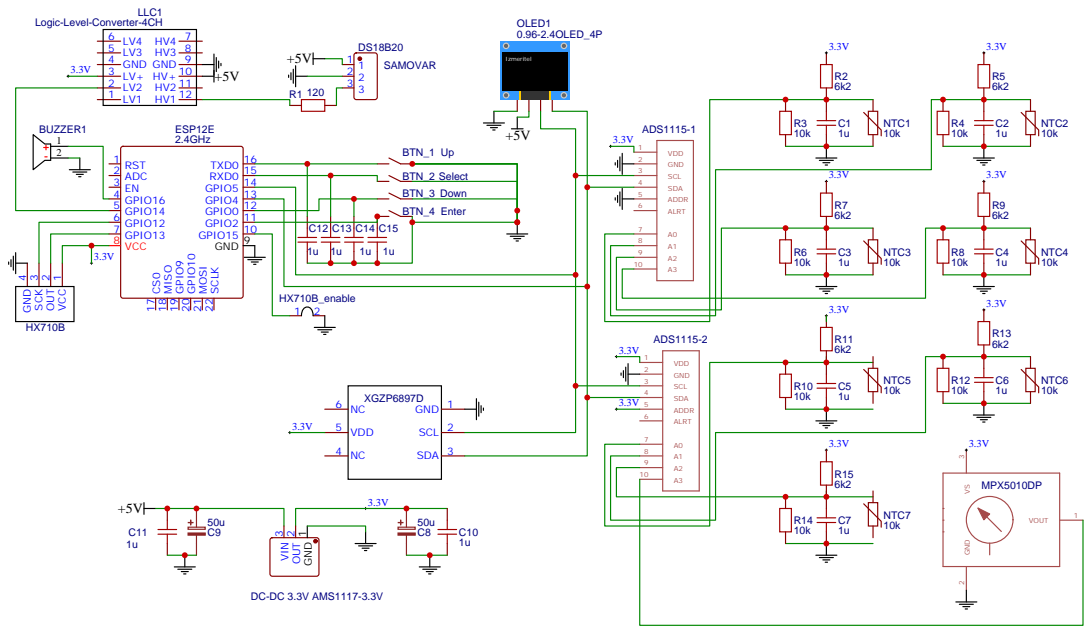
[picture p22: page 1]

DC-DC 3.3V AMS1117-3.3V GND ¹ OUT 2 VIN ³

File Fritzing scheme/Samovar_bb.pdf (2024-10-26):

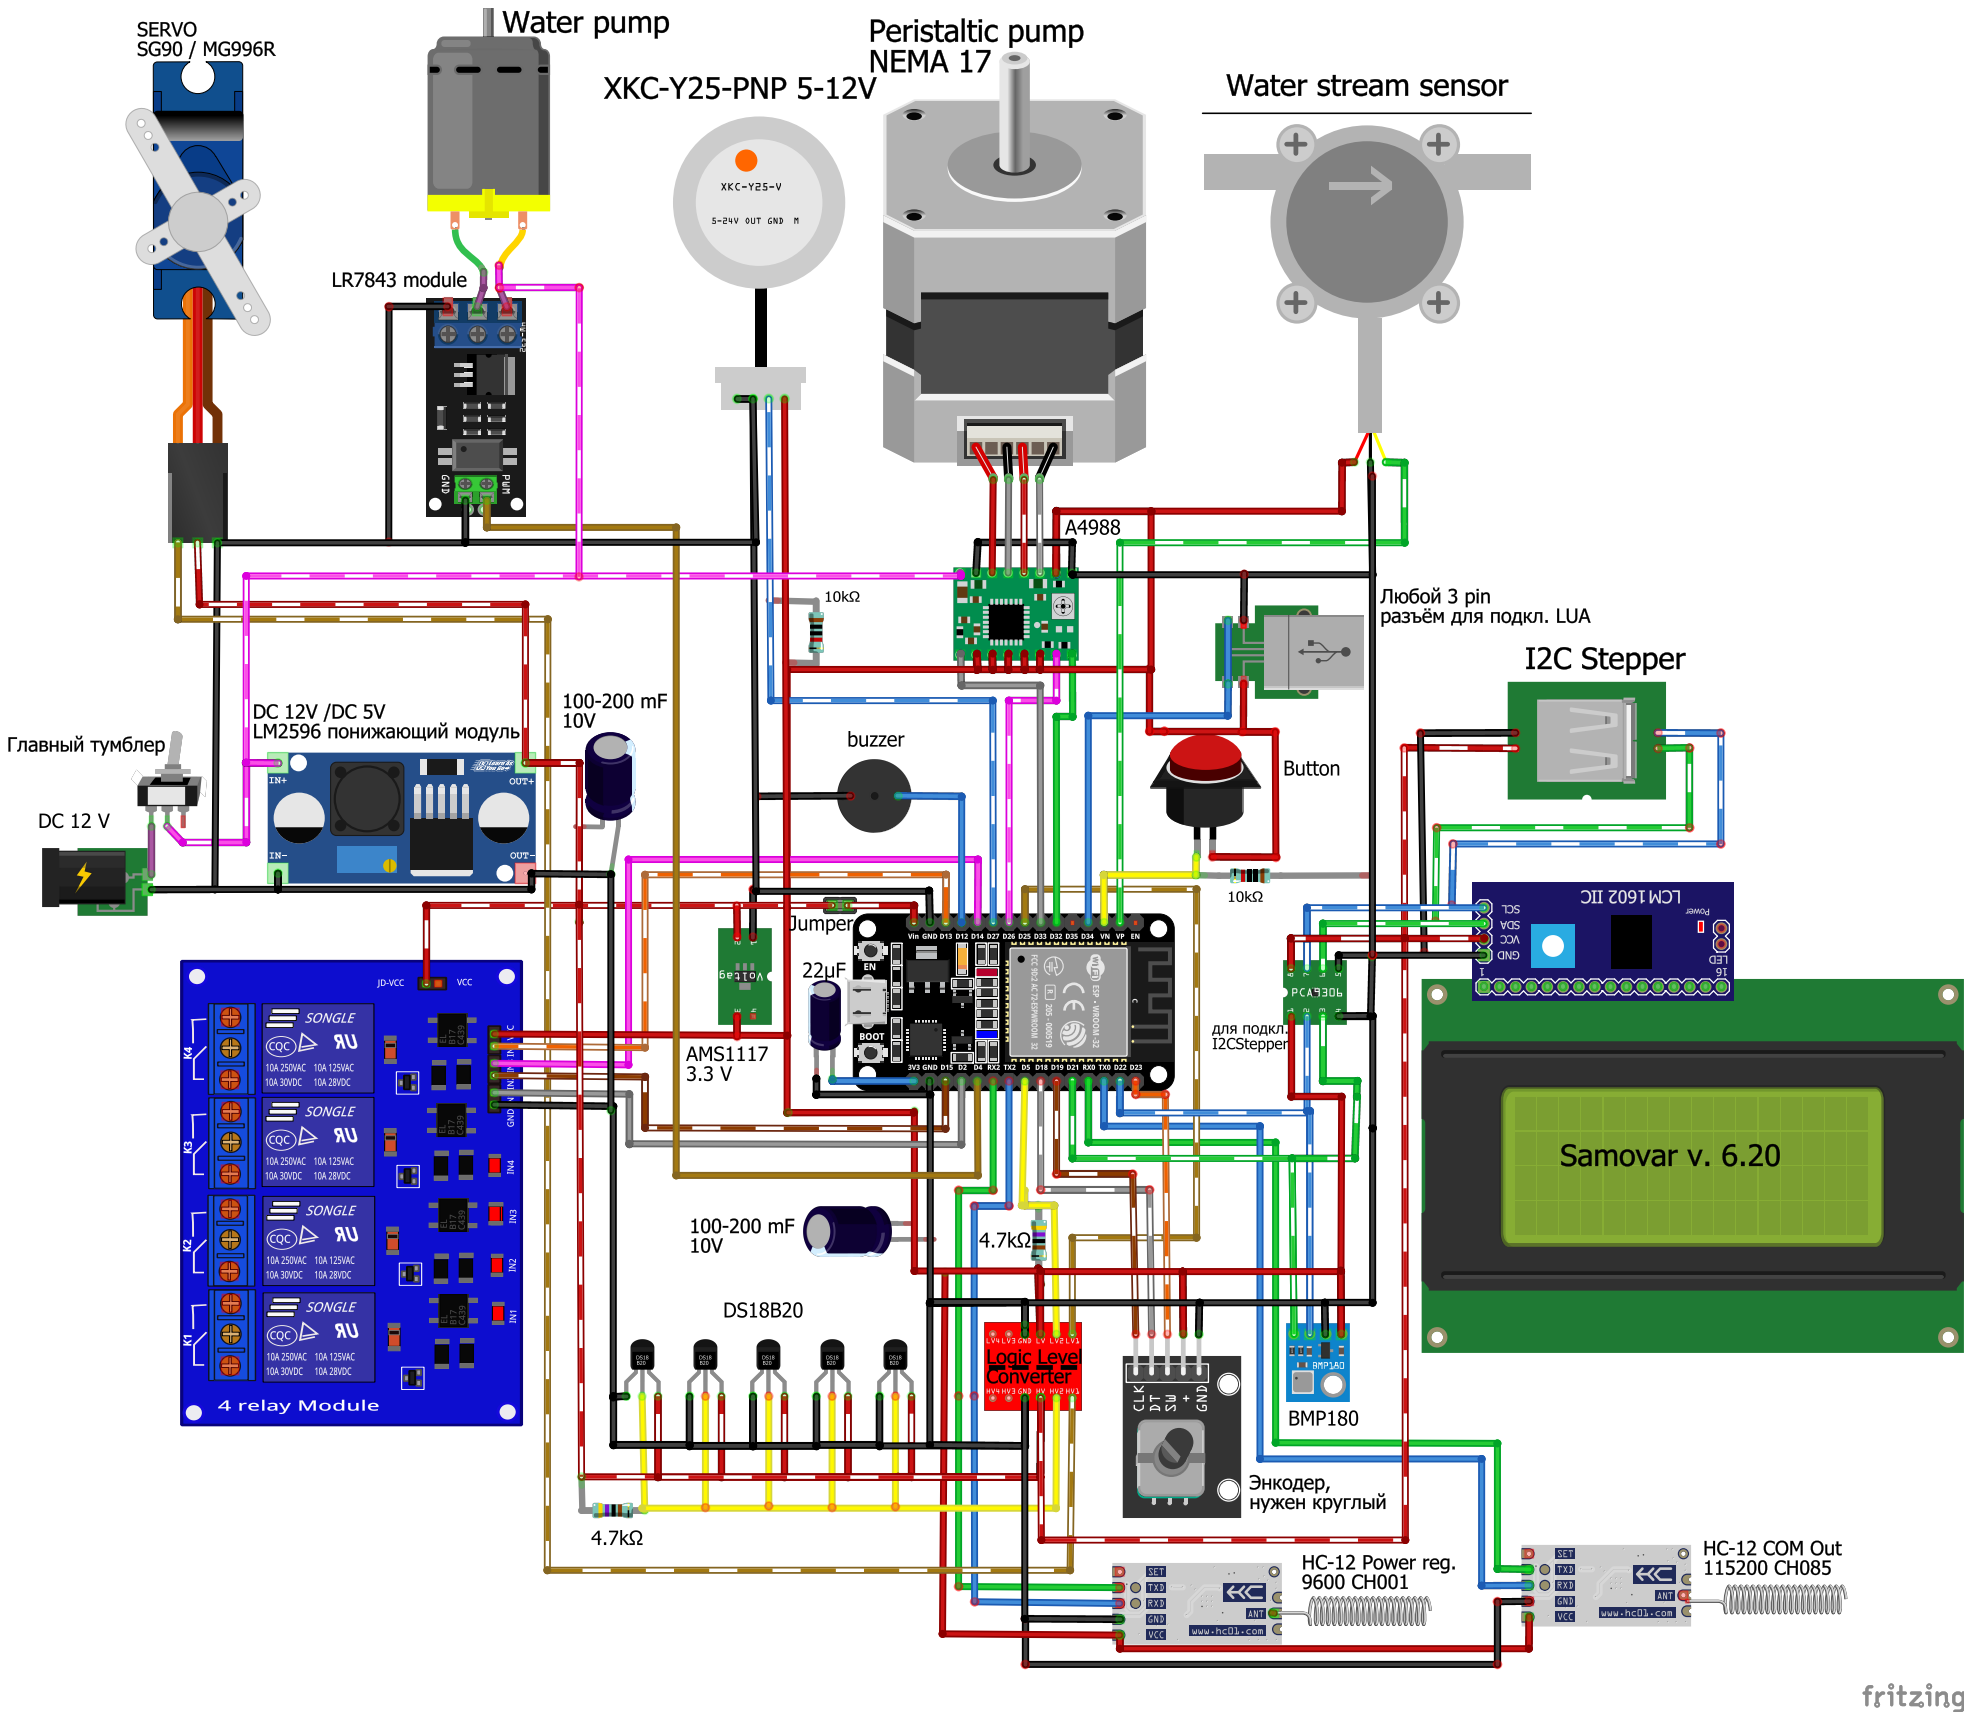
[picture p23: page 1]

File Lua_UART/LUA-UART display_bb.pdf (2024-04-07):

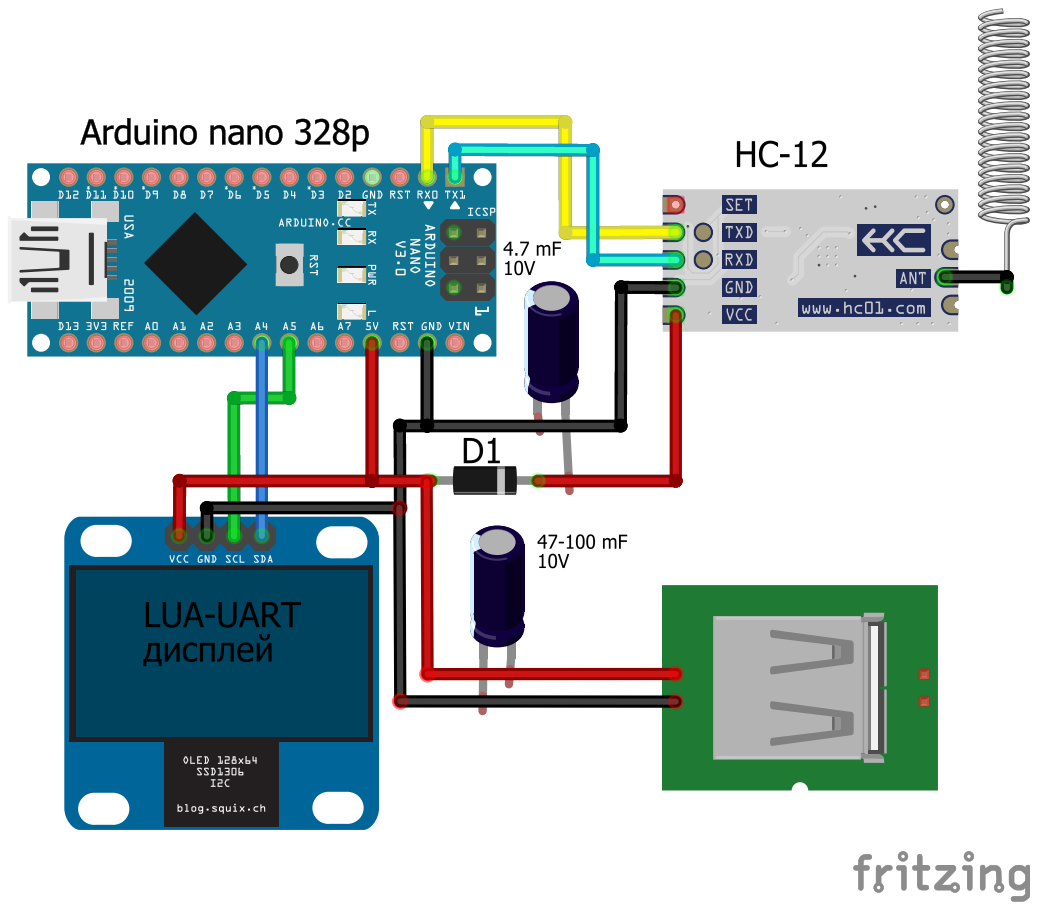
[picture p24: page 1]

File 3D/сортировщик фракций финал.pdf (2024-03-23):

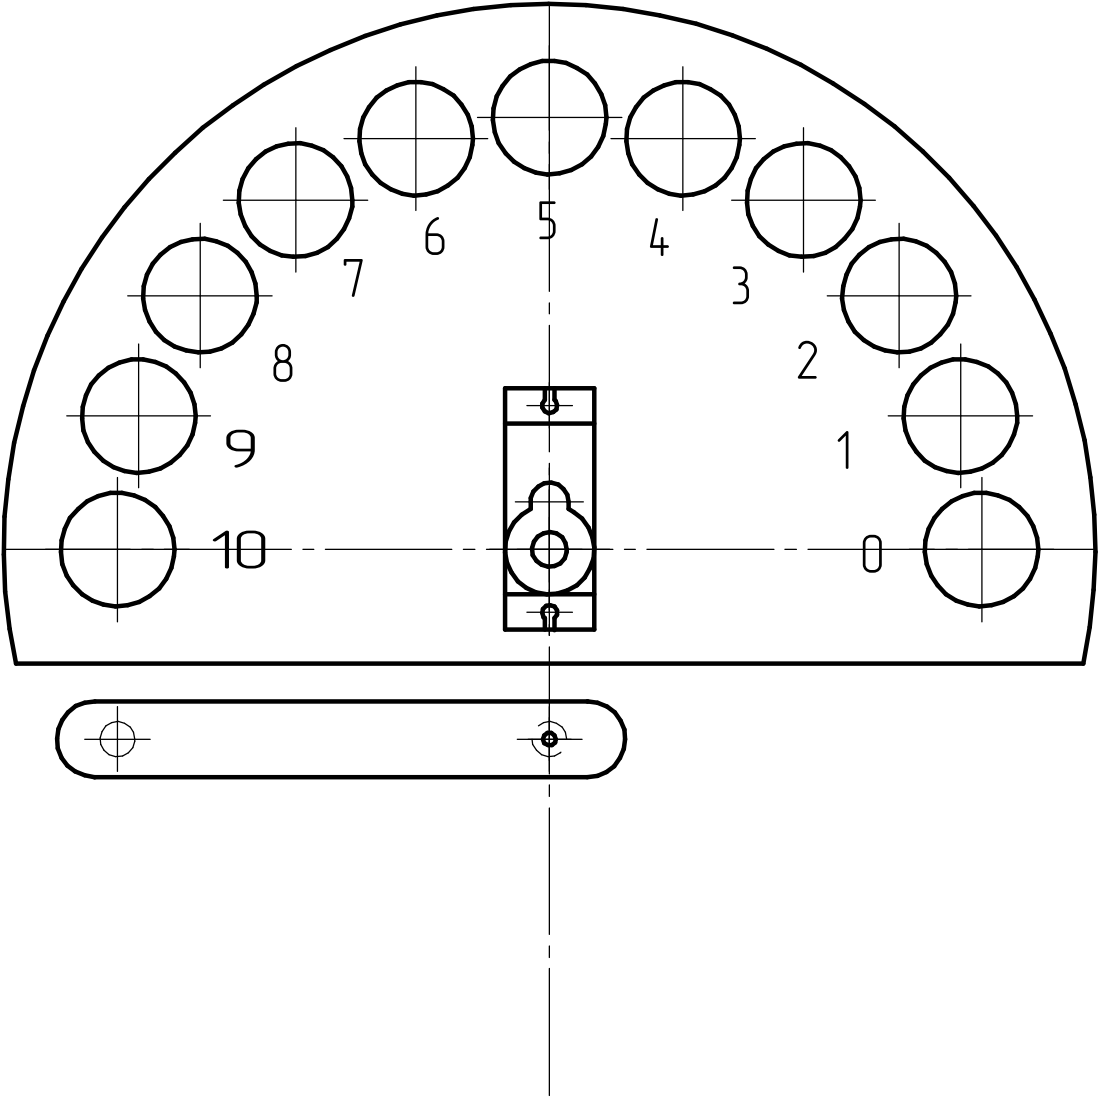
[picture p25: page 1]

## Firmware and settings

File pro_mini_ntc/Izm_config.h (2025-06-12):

// Основные настройки проекта
#define ENABLE_OTA             // OTA-обновление
#define ENABLE_WIFI            // Работа с WiFi
#define ENABLE_WEB_SERVER      // Веб-сервер
#define ENABLE_MQTT            // Управление через MQTT
#define ENABLE_OLED_DISPLAY
#define FIRST_DISP 100          // Первый выводимый дисплей 0 - три температуры и давление, 1 - остальные температуры, 99-зуммер, 100 - все Т и Р

// Настройки по умолчанию для WiFi
#define defaultSSID "" // Ссид и пароль по умолчанию, позволяет использовать два набора, первый можно сохранить в EEPROM 
#define defaultPass "" // через WEB интерфейс, это второй по ходу загрузки

// Настройки по умолчанию для MQTT
#define MQTT_SERVER "192.168.0.150"     // Адрес брокера или IP
#define MQTT_PORT 1883                    // Порт
#define MQTT_USER ""
#define MQTT_PASSWORD ""
#define MQTT_ATTEMPTS 2                   // Попытки подключения при инициализации
#define MQTT_RECONNECTION false           // Пытаться переподключиться при потере соединения
#define MQTT_TIME_PUBLICATION 1000       // Период публикаций, миллисекунд
#define MQTT_TOPIC_TEMP "izm/temp" // Топик для температур
#define MQTT_TOPIC_PRESS "izm/pressure" // Топик для давлений
#define MQTT_TOPIC_ALC "izm/alc"   // Топик для спиртометра
#define MQTT_TOPIC_STATUS "izm/status"   // Топик текущего статуса

// Константы для пинов
#define pin_spk 16          // пин зуммера
#define BtnEnter 0          // кнопка действия: на 1 экране отображения сброс дрейфа нуля датчика давления
#define BtnSel 2            // кнопка переключения экранов отображения
#define BtnUp 1             // кнопка +
#define BtnDwn 3            // кнопка -
#define Pin040DR1 15        // перемычка для определения наличия 040DR1
#define PinSCLK 12          // Ноги для 040DR1
#define PinDOUT 13
#define pin_onewire 14      // Pin передачи по протоколу 1Ware 

//1 и 3 - TX0/RX0, 4 и 5 I2C. Свободные пины: A0 (0-1В)
#define XGZP6897D_K 512 
/*pressure_range (kPa)   K value
  131<P≤260               32
  65<P≤131                64
  32<P≤65                 128
  16<P≤32                 256
  8<P≤16                  512
  4<P≤8                   1024
  2≤P≤4                   2048
  1≤P<2                   4096
  P<1                     8192*/
#define PRESSURE_MPX_ENABLE 0 // Наличие подключенного датчика MPX
#define PRESSURE_HX710B_ENABLE 0 // -||- 40DR
#define DEFAULT_PRESSURE 0 // Датчик д. по умолчанию 0- нет, XGZP6897D = 1, MPX10DP = 2, HX710B =3
//EEPROM
#define EEPROM_SIZE 512
//----------------------------------------- Работа с EEPROM ---------------------------------------------------------------
 #define EepromKey 2      // ключ EEPROM 0-255, менять для сброса EEPROM
 #define  U33_EAdr 1              // 4 байт float
 #define  Uref_EAdr 5             // 4 байт float
 #define  R62_EAdr 9              // 4 байт float
 #define  R10_EAdr 13             // 4 байт float
 #define  B25_EAdr 17             // 4 байт float
 #define  dPress_1_EAdr 21        // 4 байт float
 #define  KTemp_1_EAdr 25         // 4 байт float
 #define  BaseTemp_1_EAdr 29      // 4 байт float
 #define  PressureBaseADS_EAdr 33 // 4 байт float
 #define  PressureQ_EAdr 37       // 4 байт float
 #define  KTemp_2_EAdr 41         // 4 байт float
 #define  BaseTemp_2_EAdr 45      // 4 байт float
 #define  HX710B_Mult_EAdr 49     // 4 байт float
 #define  KTemp_3_EAdr 53         // 4 байт float
 #define  BaseTemp_3_EAdr 57      // 4 байт float
 #define  dPress_3_EAdr 61        // 4 байт float
 #define  m_adc_EAdr 65           // 302 байт 151*2
 #define  N_dPressAlc_EAdr 367    // 4 байт float
 #define  k_Alc_T_EAdr 371        // 4 байт float
 #define  k_Alc_EAdr 375          // 4 байт float
 
// Адреса EEPROM для Wi-Fi
#define SSID_ADDR 379             // 9 байта (SSID + нулевой символ)
#define PASS_ADDR 388             // 9 байта (пароль + нулевой символ)
#define WIFI_SAVED_FLAG_VALUE 1   // Значение флага, указывающее, что параметры WIFI были сохранены
#define WIFI_SAVED_FLAG_ADDR 483        // 1 байт (флаг сохранения MQTT)

// Адреса EEPROM для MQTT
#define MQTT_SERVER_ADDR 397            // 32 байта (адрес сервера + нулевой символ)
#define MQTT_PORT_ADDR 429              // 4 байт (порт MQTT, максимум 65535)
#define MQTT_USER_ADDR 433              // 9 байта (пользователь + нулевой символ)
#define MQTT_PASSWORD_ADDR 442          // 9 байта (пароль + нулевой символ)
#define MQTT_ATTEMPTS_ADDR 451          // 1 байт (количество попыток подключения)
#define MQTT_RECONNECTION_ADDR 452      // 1 байт (флаг переподключения)
#define MQTT_TIME_PUBLICATION_ADDR 453  // 4 байта (период публикаций, long)
#define MQTT_SAVED_FLAG_ADDR 457        // 1 байт (флаг сохранения MQTT)
#define MQTT_SAVED_FLAG_VALUE 1         // Значение флага, указывающее, что параметры MQTT были сохранены

#define R25_EAdr 458
#define R100_EAdr  462
#define Alc_tar_EAdr     466  // Пример адреса, подберите под свою конфигурацию
#define T_target_EAdr    470
#define spk_max_count_EAdr 474
#define spk_on_EAdr      478
#define PRESSURE_MPX_ENABLE_ADDR 482
#define PRESSURE_HX710B_ENABLE_ADDR 484
#define DEFAULT_PRESSURE_ADDR 485
#define XGZP6897D_K_ADDR 486
// Адрес свободной ячейки EEPROM 488

#if defined(ENABLE_WEB_SERVER) || defined(ENABLE_MQTT) || defined(ENABLE_OTA)
#define ENABLE_WIFI 
#endif

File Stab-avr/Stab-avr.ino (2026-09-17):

//Регулятор ТЭНа полуволнами с программным детектором нуля
//--https://github.com/JohnJohnov/Stab-avr
//--https://alcodistillers.ru/forum/viewtopic.php?id=1549
//--JohnJohnov-----------------------
//--использован код OldBean----------
//--v0.2-------------------
//--добавлен дисплей
//--v0.3-------------------
//--ПИД-подстройка частоты сети по переходу через ноль
//--опрос кнопок
//--режим разгона
//--v0.4-------------------
//--выборки набираются за целое количество периодов
//--v0.5-------------------
//--оптимизация
//--v0.6-------------------
//--организована корректная обработка отсутствия сети
//--v0.7-------------------
//--исправлена ошибка выставления мощности менее 200Вт
//--битовые переменные упакованы в структуры
//--убрано ненужное мерцание символов на дисплее
//--добавлена возможность вернуть установленную мощность после экстренного отключения (идея d.styler)
//--v0.8-------------------
//--менюшка при возвращении уст.мощности после экстр.откл.
//--v0.81------------------
//--сделано выравнивание значений по правому краю
//--перекомпонован дежурный экран
//--выводится установленная мощность в Вт и процентах
//--напряжение сети выводится с одним знаком после запятой
//--v0.9-------------------
//--оптимизация кода
//--переход на более другую библиотеку дисплея
//--русский шрифт
//--номинальная мощность устанавливается/записывается/выбирается в начальном меню
//--уставки, выбираемые в меню после экстр.откл., могут быть записаны в EEPROM
//--v0.95------------------
//--исправлены ошибки
//--значение задержки для защиты от дребезга вынесено в дефайны
//--v0.96------------------
//--исправлены ошибки, оптимизирован код
//--расширены границы диапазона сетевой частоты для поддержки канадского коллеги
//--добавлена поддержка универсального протокола общения с управляющей программой
//--v0.97------------------
//--добавлена поддержка протокола общения с Samovar (начало посылки кириллицей)
//--добавлено моргание светодиода в отладочных целях
//--добавлен таймаут менюшек
//--добавлена поддержка протокола общения с РМВ-К
//--логотип
//--оптимизация кода
//--v0.98------------------
//--добавлен альтернативный интерфейс с большими символами для опытных пользователей
//--изменена работа с EEPROM
//--повышена точность регулировки (до 0,2%)
//--оптимизация кода
//--v0.98.4----------------
//--оптимизация кода
//--уменьшение размера кода для поддержки ATmega168
//--добавлено отключение разгона внешним сигналом
//--добавлено аварийное отключение нагрузки внешним сигналом
//--работа с портами организована через регистры без использования ардуиновских функций
//--
//--
//-------------------------
#include <Wire.h>
#include <EEPROM.h>
//#include <avr/eeprom.h>
#include <ASOLED.h>
#include <util/atomic.h>
//
#define VERSION "v0.98"   // Версия скетча
#define VERSION_LEN 5     // Длина версии скетча в символах для правильного вывода на дисплей
//
//================================================================
//===========Настраиваемые параметры==============================
//================================================================
//#define LOGO              // Раскомментить для отображения логотипа
//#define Debug           // Раскомментить для дебажения
//#define LED_debug       // Раскомментить для вывода на светодиод сигнала управления твердотельным реле
#define INTERFACE_ALT     // Раскомментить для включения альтернативного интерфейса с большими символами
#define High_level_triac  // Раскомментить, если твердотельное реле ТЭНа управляется ВЫСОКИМ уровнем, иначе НИЗКИМ
#define High_level_relay  // Раскомментить, если контактное реле ТЭНа управляется ВЫСОКИМ уровнем, иначе НИЗКИМ
//#define NOT_LM358       // Раскомментить, если в датчике напряжения стоит НЕ LM358, а rail-to-rail операционник
//#define DisplayReset      // Раскомментить, если используется вывод сброса дисплея
#define DEBOUNCE 26       // Значение для обеспечения защиты от дребезга кнопок DEBOUNCE=1 + <задержка в ms>/10
//
//#define U_LINE_FREQ_60    // Раскомментить, если частота сети 60Гц, иначе - 50Гц
//
#define U_LINE 230        // Номинальное значение действующего напряжения в сети, для которого указана номинальная мощность ТЭНа
#define U_MIN 100         // Значение напряжения в сети, ниже которого сеть считается аварийной
#define U_RAZGON 220      // Уставка напряжения (режим РМВ-К), выше которой включается разгон
#define U_LINE_Q 52900    // Квадрат номинала сети, для которого указана номинальная мощность ТЭНа
//
#define MENU_TIMEOUT 40  // Таймаут выхода из меню в секундах (не более 255)
//
//=====Настройки коммуникации по последовательному порту============
#define USE_USART           // Раскомментить для инициализации общения стаба с внешним контроллером
  #ifdef USE_USART
  #define USE_RMVK        // Раскомментить для включения общения с внешним контроллером по протоколу Samovar или РМВ-К (см. REG_MODE_VOLT)
//  #define REG_MODE_VOLT   // Раскомментить для работы в вольтах по протоколу РМВ-К, иначе - в ваттах по протоколу Samovar
#endif
//==================================================================
//==================================================================
//
#ifdef U_LINE_FREQ_60
  #define LINE_FREQ 129 // Определяет начальную частоту для фазовой автоподстройки частоты сети (60,1Гц)
  #define PSUM_MAX 60   // Количество периодов для набора отсчетов АЦП (60 - это за 1 сек, это порядка 5000 отсчетов)
  #define P_TIME_MAX 120  // Количество полупериодов сети в секунду для отсчета времени
#else
  #define LINE_FREQ 155   // Определяет начальную частоту для фазовой автоподстройки частоты сети (50,08Гц)
  #define PSUM_MAX 50     // Количество периодов для набора отсчетов АЦП (50 - это за 1 сек, это порядка 5000 отсчетов)
  #define P_TIME_MAX 100  // Количество полупериодов сети в секунду для отсчета времени
#endif
//
//=============вход АЦП================
#define pin_VACin 0       //  Пин входа измеряемого напряжения (A0)
//
//===========входные выводы============
#define pin_PC_STATE(pin) (~(PINC >> (pin - 14)) & 1) // Запрос состояния вывода со сдвигом и инверсией результата
#define pin_PC_InPullUp(pin) DDRC &=~(1 << (pin - 14)); PORTC |=(1 << (pin - 14)) // Инициализация входа с подтяжкой к VCC
//
#define pin_RAZGON_OFF 17 // Пин входа отключения разгона (A3 - это D17/PC3, при изменении подредактировать следующие два макроса)
#define pin_RAZGON_OFF_INIT pin_PC_InPullUp(pin_RAZGON_OFF) // Определяем вывод отключения разгона, как вход и подтягиваем его внутренним резюком к VCC
#define pin_RAZGON_OFF_STATE pin_PC_STATE(pin_RAZGON_OFF)   // Читаем состояние пина и переводим в булев формат с учетом инверсии (активный - низкий)
//
#define pin_STAB_OFF 16   //  Пин входа отключения стабилизатора (A2 - это D16/PC2, при изменении подредактировать следующие два макроса)
#define pin_STAB_OFF_INIT pin_PC_InPullUp(pin_STAB_OFF) // Определяем вывод останова стаба, как вход и подтягиваем его внутренним резюком к VCC
#define pin_STAB_OFF_STATE pin_PC_STATE(pin_STAB_OFF)   // Читаем состояние пина и переводим в булев формат с учетом инверсии (активный - низкий)
//
//===========вЫходные выводы===========
#define pin_PD_Out(pin) DDRD |=(1 << pin)   // Инициализация выхода
#define pin_PD_HIGH(pin) PORTD |=(1 << pin) // Установка выхода
#define pin_PD_LOW(pin) PORTD &=~(1 << pin) // Сброс выхода
#define pin_PD_INV(pin) PORTD ^=(1 << pin)  // Инверсия выхода
//
#define pin_OLEDres 2     //  Пин сброса OLED индикатора.
#define pin_OLEDres_INIT pin_PD_Out(pin_OLEDres)
#define pin_OLEDres_HIGH pin_PD_HIGH(pin_OLEDres)
#define pin_OLEDres_LOW pin_PD_LOW(pin_OLEDres)
//
#define pin_TOut 4        //  Пин выхода управления ТЭНом (на твердотельное реле)
#define pin_TOut_INIT pin_PD_Out(pin_TOut)
#define pin_TOut_HIGH pin_PD_HIGH(pin_TOut)
#define pin_TOut_LOW pin_PD_LOW(pin_TOut)
//
#define pin_TRelay 6      //  Пин выхода управления ТЭНом (на контактное реле в режиме максимальной мощности)
#define pin_TRelay_INIT pin_PD_Out(pin_TRelay)
#define pin_TRelay_HIGH pin_PD_HIGH(pin_TRelay)
#define pin_TRelay_LOW pin_PD_LOW(pin_TRelay)
//
//===========тестовые выводы===========
#define pin_ZeroOut 5     //  Пин выхода импульса ноля (D5 - PD5)
#define pin_ZeroOut_INIT pin_PD_Out(pin_ZeroOut)
#define pin_ZeroOut_INV pin_PD_INV(pin_ZeroOut)
#define pin_ZeroOut_HIGH pin_PD_HIGH(pin_ZeroOut)
#define pin_ZeroOut_LOW pin_PD_LOW(pin_ZeroOut)
//
#define pin_DebugOut 7    //  Пин для отладки (D7 - PD7)
#define pin_DebugOut_INIT pin_PD_Out(pin_DebugOut)
#define pin_DebugOut_INV pin_PD_INV(pin_DebugOut)
#define pin_DebugOut_HIGH pin_PD_HIGH(pin_DebugOut)
#define pin_DebugOut_LOW pin_PD_LOW(pin_DebugOut)
//
#define pin_TestOut 3     //  Пин для отладки (D3 - PD3)
#define pin_TestOut_INIT pin_PD_Out(pin_TestOut)
#define pin_TestOut_INV pin_PD_INV(pin_TestOut)
#define pin_TestOut_HIGH pin_PD_HIGH(pin_TestOut)
#define pin_TestOut_LOW pin_PD_LOW(pin_TestOut)
//
//===========выводы подключения кнопок===========
#define pin_PB_STATE(pin) (~(PINB >> (pin - 8)) & 1) // Запрос состояния вывода со сдвигом и инверсией результата
#define pin_PB_InPullUp(pin) DDRB &=~(1 << (pin - 8)); PORTB |=(1 << (pin - 8)) // Инициализация входа с подтяжкой к VCC
#define pin_PB_OutLOW(pin) DDRB |=(1 << (pin - 8)); PORTB &=~(1 << (pin - 8))   // Инициализация выхода и сброс его
//
#define pin_butt_1 10     // Пин кнопки "Р-". Уменьшение уставки мощности. (D10 - PB2)
#define pin_butt_1_INIT pin_PB_InPullUp(pin_butt_1) // Определяем вывод кнопки, как вход и подтягиваем его внутренним резюком к VCC
#define pin_butt_1_STATE pin_PB_STATE(pin_butt_1)   // Читаем состояние пина и переводим в булев формат с учетом инверсии (активный - низкий)
//
#define pin_butt_2 9      // Пин кнопки "Р+". Увеличение уставки мощности. (D9 - PB1)
#define pin_butt_2_INIT pin_PB_InPullUp(pin_butt_2) // Определяем вывод кнопки, как вход и подтягиваем его внутренним резюком к VCC
#define pin_butt_2_STATE pin_PB_STATE(pin_butt_2)   // Читаем состояние пина и переводим в булев формат с учетом инверсии (активный - низкий)
//
#define pin_butt_3 12     // Пин кнопки "Стоп". Экстренное отключение ТЭНа. (D12 - PB4)
#define pin_butt_3_INIT pin_PB_InPullUp(pin_butt_3) // Определяем вывод кнопки, как вход и подтягиваем его внутренним резюком к VCC
#define pin_butt_3_STATE pin_PB_STATE(pin_butt_3)   // Читаем состояние пина и переводим в булев формат с учетом инверсии (активный - низкий)
//
#define pin_butt_4 11     // Пин кнопки "Разгон". Включение/отключение разгона. (D11 - PB3)
#define pin_butt_4_INIT pin_PB_InPullUp(pin_butt_4) // Определяем вывод кнопки, как вход и подтягиваем его внутренним резюком к VCC
#define pin_butt_4_STATE pin_PB_STATE(pin_butt_4)   // Читаем состояние пина и переводим в булев формат с учетом инверсии (активный - низкий)
//
#define pin_buttGND 8     // Пин временного общего провода для подключения кнопок. (D8 - PB0)
#define pin_buttGND_INIT pin_PB_OutLOW(pin_buttGND) // Определяем вывод, как вЫход и устанавливаем низкий уровень
//
//===============бортовой светодиод==============
#define pin_LED 13  // Бортовой светодиод подключен к выводу D13 (PB5)
#define pin_LED_INIT pin_PB_OutLOW(pin_LED)       // Определяем вывод, как вЫход и устанавливаем низкий уровень
#define TURN_LED_ON  PORTB |=(1 << (pin_LED - 8)) // Включаем светодиод
#define TURN_LED_OFF PORTB &=~(1 << (pin_LED - 8))// Выключаем светодиод
//
//==============управление релюшками=============
#ifdef High_level_triac // управление твердотельным реле высоким уровнем
#define TURN_SSR_ON pin_TOut_HIGH   // Включаем ТЭН
#define TURN_SSR_OFF pin_TOut_LOW   // Выключаем ТЭН
#else // управление твердотельным реле низким уровнем
#define TURN_SSR_ON pin_TOut_LOW    // Включаем ТЭН
#define TURN_SSR_OFF pin_TOut_HIGH  // Выключаем ТЭН
#endif
//
#ifdef High_level_relay // управление контактным реле высоким уровнем
#define TURN_RELAY_ON pin_TRelay_HIGH   // Включаем ТЭН
#define TURN_RELAY_OFF pin_TRelay_LOW   // Выключаем ТЭН
#else // управление контактным реле низким уровнем
#define TURN_RELAY_ON pin_TRelay_LOW    // Выключаем ТЭН
#define TURN_RELAY_OFF pin_TRelay_HIGH  // Включаем ТЭН
#endif
//
//========коэффициенты для ПИД-регулировки=======
#define Kp 2      // Коэффициент пропорциональности для ПИД-подстройки ФЧ сети (степень двойки для регистрового сдвига)
#define Ki 5      // Интегральный коэффициент для ПИД-подстройки ФЧ сети (степень двойки для регистрового сдвига)
#define Kd 1      // Дифференциальный коэффициент для ПИД-подстройки ФЧ сети (степень двойки для регистрового сдвига)
#define Km 6      // Коэффициент для целочисленной математики (степень двойки для регистрового сдвига)
#define PHASE 8   // сдвиг фаз между детекцией ноля и прерыванием таймера (в тиках таймера)
#define T_MAX 180 // ограничение максимальной длительности полупериода в тиках таймера
#define T_MIN 100 // ограничение минимальной длительности полупериода в тиках таймера
//
//================прочие константы===============
#define ZSUM_MAX 5000 // Количество отсчетов АЦП без детекции ноля (5000 отсчетов это порядка 1 сек)
#define U_ZERO 512    // Значение нуля АЦП для двуполярного сигнала с постоянной составляющей на выходе ОУ
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
void loop(void) {
//
  if (fl.sum) { //==========Обработка данных от АЦП и корректировка выдаваемой мощности============
    // S-27: атомарно захватываем разделяемые ISR(ADC) переменные до расчёта
    uint32_t l_U_sum;
    uint16_t l_sc_sum;
    uint16_t l_PDMust;
    ATOMIC_BLOCK(ATOMIC_RESTORESTATE) {
      l_U_sum  = U_sum;
      l_sc_sum = sc_sum;
      l_PDMust = PDMust; // S-28: атомарно читаем PDMust (пишется loop, читается ISR TIMER2)
    }
#ifdef NOT_LM358
    // 0,55 - Коэффициент нормирования ((380/512)^2, 380В максимальное амплитудное) для Rail-to-Rail операционника
    l_U_sum /= l_sc_sum;    //Ненормированный квадрат среднеквадратичного
    l_U_sum *= 0.55;        //Нормированный квадрат среднеквадратичного
#else
    // 3 - Коэффициент нормирования ((380/220)^2, 380В максимальное амплитудное) для стандартно установленного LM358
    l_U_sum *= 3;           //Нормированная сумма квадратов среднеквадратичного
    l_U_sum /= l_sc_sum;    //Нормированный квадрат среднеквадратичного
#endif
    if (l_U_sum > 65025) l_U_sum = 65025; // Сеть выше 255В считаем равной 255В, квадрат обязан влезать в 16-битный делитель calc_proportion
    //=====Корректируем pdm
//    uint32_t tmp; // Величины великоваты, чтобы попасть в размерность приходится считать аккуратно
//    //    pdm = U_LINE_Q*PDMust/(U_sum);
//    tmp = (long)U_LINE_Q * 2;
//    tmp *= (long)PDMust;
//    tmp /= U_sum;
//    tmp++;
//    tmp /= 2;
    //
#ifdef REG_MODE_VOLT
    uint16_t tmp;
    if (l_PDMust && (volt_to_PDM(Vust) == l_PDMust)) {  // Уставка задана в вольтах - считаем pdm сразу из квадратов напряжений, с одним округлением
      tmp = calc_proportion((uint16_t)Vust * Vust, CICLE, l_U_sum);
    }
    else {                                // Уставку меняли кнопками - считаем от PDMust
      tmp = calc_proportion(l_PDMust, U_LINE_Q, l_U_sum);
    }
#else
    uint16_t tmp = calc_proportion(l_PDMust, U_LINE_Q, l_U_sum);
#endif
    //
    if (tmp > CICLE || fl.razg) { // Следим, чтобы pdm не превышала CICLE
      // S-26/28: атомарно пишем pdm и fl.Ulow (разный байт fl, но fl.Ulow соседствует с fl.Tout/TRelay из ISR)
      ATOMIC_BLOCK(ATOMIC_RESTORESTATE) {
        pdm = CICLE;
        fl.Ulow = !fl.razg; // Или напряжение сети не позволяет выдать установленный уровень мощности, или разгон
      }
    }
    else {
      ATOMIC_BLOCK(ATOMIC_RESTORESTATE) {
        fl.Ulow = 0;
        pdm = tmp; // S-28: атомарно пишем 16-бит pdm
      }
    }

    // Проверяем величину напряжения
    l_U_sum *= (long)400;             // Произведем некоторое математическое колдунство,
    l_U_sum = sqrt(l_U_sum);         // чтобы получить один знак после запятой без float
    l_U_sum++; l_U_sum /= 2;        // и с правильным округлением.
    U_real_dec = l_U_sum % 10;       // Среднеквадратичное (дробная часть)
    U_real = l_U_sum / 10;           // Среднеквадратичное (целая часть)
    //
    // Контролируем значение
    if ( U_real < U_MIN ) { //Действующее напряжение сети ниже U_MIN - отключим ТЭН (авария)
      // S-26/28: атомарно пишем fl.Udown и pdm
      ATOMIC_BLOCK(ATOMIC_RESTORESTATE) {
        fl.Udown = 1;       //поставим флажок низкого сетевого
        pdm = 0;            //выключим твердотельное реле
      }
      stop_razgon();
    }
    else {
      ATOMIC_BLOCK(ATOMIC_RESTORESTATE) {
        fl.Udown = 0;
      }
    }
    ATOMIC_BLOCK(ATOMIC_RESTORESTATE) {
      fl.sum = 0; // S-26: атомарный сброс fl.sum (ISR(ADC) пишет тот же байт fl)
      fl.dspNewData = 1;  //Обновление информации на дисплее
    }
  } //======================Обработка данных от АЦП и корректировка выдаваемой мощности============
  //
  if (fl.dspNewData) { //========================Вывод информации на дисплей=============
    boolean l_dspRefresh;
    ATOMIC_BLOCK(ATOMIC_FORCEON) { // S-26: флаги снимаем ДО отрисовки - запрос, пришедший из ISR во время рисования, останется на следующий проход
      l_dspRefresh = fl.dspRefresh;
      fl.dspRefresh = 0;
      fl.dspNewData = 0;
    }
    if (l_dspRefresh) {
      RefreshMenu(); //Обновляем дисплей, если надо
    }
    //
    switch (cnt_dspMenu) { //=====Проверяем режимы меню
      case 2:  {  //=============Если мы в начальном меню, то...
        static uint16_t Pnomold = 0;
        if (!Pnom || Pnom > 9999) {
          Pnomold = Pnom;
#ifdef INTERFACE_ALT
          ASOled.printString_12x16(F("****"), X_position (3,0,12), 0);
#else
          ASOled.printString_6x8(F("****"), X_position (6), 1);
#endif
        }
        else if ((Pnomold != Pnom) || l_dspRefresh) {
          Pnomold = Pnom;
#ifdef INTERFACE_ALT
          ASOled.printString_12x16(F("    "), X_position (3,0,12), 0);
          ASOled.printNumber((long)Pnom, X_position (6,Pnom,12), 0);
#else
          ASOled.printString_6x8(F("    "), X_position (6), 1);
          ASOled.printNumber((long)Pnom, X_position (9,Pnom), 1);
#endif
        }
        break;
      }
      case 1:  {  //=============Если мы в меню выбора уставки, то...
        static uint16_t PDMold = 0;
        if ((PDMold != PDMset[0][cnt_PDMcount]) || l_dspRefresh) {
          PDMold = PDMset[0][cnt_PDMcount];
          uint16_t p = calc_proportion(PDMold); // Считаем уставку с округлением
#ifdef INTERFACE_ALT
          ASOled.printString_12x16(F("    "), X_position (3,0,12), 0);
          ASOled.printNumber((long)p, X_position (6,p,12), 0);
#else
          ASOled.printString_6x8(F("    "), X_position (6), 1);
          ASOled.printNumber((long)p, X_position (9,p), 1);
#endif
          if (PDMset[1][cnt_PDMcount]) {  // Если значение записано в EEPROM
            ASOled.printString_6x8(F("R"), X_position (20), 1);     // поставим значок
          }
          else {
          ASOled.printString_6x8(F(" "), X_position (20), 1);   // а если не записано - уберем
          }
        }
        break;
      }
      default: {  //=============А если не в меню, то...
#ifdef INTERFACE_ALT
    #define str_Ureal_big 0
      #define str_Ureal 1
    #define str_ust_big 3
    #define str_ust 4
        #define str_Ustat 2
    #define str_Razgon 5
        #define str_Pnom 6
        #define str_Relay 7
#else
    #define str_Ureal 0
        #define str_Ustat 1
        #define str_ust 3
        #define str_Pnom 6
        #define str_Razgon 4
        #define str_Relay 7
#endif
        //
        if (l_dspRefresh) {  //Обновляем дисплей
          ASOled.clearDisplay();
#ifdef INTERFACE_ALT
          ASOled.printString_6x8(F("Вт       ,  %"), X_position (8), str_ust);
#else
          ASOled.printString_6x8(F("Руст      Вт;    ,  %"), 0, str_ust);
#endif
          ASOled.printString_6x8(F("Напр.сети        ,  В"), 0, str_Ureal);
          ASOled.printString_6x8(F("Ном. мощность      Вт"), 0, str_Pnom);
          ASOled.printNumber((long)Pnom, X_position (17,Pnom), str_Pnom);
//          ASOled.printString_6x8(F("Реле "), X_position (0), str_Relay);
        }
        //
        static uint16_t U_real_old = 0;
        if ((U_real_old != U_real) || l_dspRefresh) {
          U_real_old = U_real;
#ifdef INTERFACE_ALT
          ASOled.printString_12x16(F("   "), X_position (7,100,12) + 5, str_Ureal_big);
          ASOled.printNumber((long)U_real_old, X_position (7,U_real_old,12) + 5, str_Ureal_big);
#else
          ASOled.printString_6x8(F("    "), X_position (13), str_Ureal);
          ASOled.printNumber((long)U_real_old, X_position (16,U_real_old), str_Ureal);
#endif
        }
        static uint8_t U_real_dec_old = 0;
        if ((U_real_dec_old != U_real_dec) || l_dspRefresh) {
          U_real_dec_old = U_real_dec;
#ifdef INTERFACE_ALT
          ASOled.printString_12x16(F(" "), X_position (9,0,12), str_Ureal_big);
          ASOled.printNumber((long)U_real_dec_old, X_position (9,0,12), str_Ureal_big);
#else
          ASOled.printNumber((long)U_real_dec_old, X_position (18), str_Ureal);
#endif
        }
        static uint16_t Pust_old = 0;
        if ((Pust_old != Pust) || l_dspRefresh) {
          Pust_old = Pust;
#ifdef INTERFACE_ALT
          ASOled.printString_12x16(F("    "), 0, str_ust_big);
          ASOled.printNumber((long)Pust_old, X_position (3,Pust_old,12), str_ust_big);
#else
          ASOled.printString_6x8(F("    "), X_position (5), str_ust);
          ASOled.printNumber((long)Pust_old, X_position (8,Pust_old), str_ust);
#endif
        }
        //
        static uint16_t PDMust_old = 0;
        if ((PDMust_old != PDMust) || l_dspRefresh) {
          PDMust_old = PDMust;
          uint32_t x = 1000*(long)PDMust_old;
          x /= CICLE;
          uint8_t percent = x / 10;    // посчитаем процент
          uint8_t percent_dec = x % 10;// посчитаем десятые процента
#ifdef INTERFACE_ALT
          ASOled.printString_12x16(F("   "), X_position (7,100,12) + 5, str_ust_big);
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

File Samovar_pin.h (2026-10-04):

#ifndef __SAMOVAR_PIN_H_
#define __SAMOVAR_PIN_H_

// Автоматическое определение типа платы
#if !defined(BOARD)
#if defined(ARDUINO_ESP32S3_DEV)
#define BOARD ESP32S3
#elif defined(ARDUINO_ESP32_LILYGO_T_RELAY)
#define BOARD LILYGO
#elif defined(ARDUINO_ESP32_DEV)
#define BOARD DEVKIT
#endif
#endif

// Если плата не определена автоматически, используем DEVKIT по умолчанию
#if not defined(BOARD)
#define BOARD DEVKIT
#endif

//**************************************************************************************************************
// Распиновка
//**************************************************************************************************************

//**************************************************************************************************************
// Пины для BME680, BMP180, BMP280
//#define BME_SCK 22   //SCL
//#define BME_MISO --  //SDO
//#define BME_MOSI 21  //SDA
//#define BME_CS --    //CS
//#define SEALEVELPRESSURE_HPA (1013.25)
//**************************************************************************************************************


//**************************************************************************************************************
//**************************************************************************************************************
//**ESP32S3**
//**в Инструменты-Плата выбрать ESP32S3 Dev module, 8Mb, 3MB APP/1.5MB FS
//**************************************************************************************************************
//**************************************************************************************************************
#if BOARD == ESP32S3
//#pragma message ("ESP32S3")
#define ENC_CLK 7 //S2
#define ENC_DT 6  //S1
#define ENC_SW 5  //KEY

#define STEPPER_STEP 16
#define STEPPER_DIR 14
#define STEPPER_EN 15

#define RELE_CHANNEL1 2             //используется для пускателя, который включает нагреватель
#define RELE_CHANNEL2 42             //в режиме "Пиво" используется для включения мешалки
#define RELE_CHANNEL3 41             //используется для клапана, открывающего/закрывающего воду охлаждения
#define RELE_CHANNEL4 40             //если не используется регулятор с управлением, выход используется для управления разгоном

#define ONE_WIRE_BUS 12

#define SERVO_PIN 10

#define BTN_PIN 47

#define LUA_PIN 4

#define ALARM_BTN_PIN 48

#define WATERSENSOR_PIN 13

#define WHEAD_LEVEL_SENSOR_PIN 19

#define LCD_SDA 8
#define LCD_SCL 9

#define RXD2 18
#define TXD2 17

#define WATER_PUMP_PIN 11

#define BZZ_PIN 39
//**************************************************************************************************************
//**************************************************************************************************************
//**ESP32S3**
//**************************************************************************************************************
//**************************************************************************************************************


//**************************************************************************************************************
//**************************************************************************************************************
//**LILYGO T-RELAY 4**
//**в Инструменты-плата выбрать ESP32 Dev module
//**************************************************************************************************************
//**************************************************************************************************************
#elif BOARD == LILYGO
//#pragma message ("LILYGO")
#define ENC_CLK 35 //S2
#define ENC_DT 39  //S1
#define ENC_SW 36  //KEY

#define STEPPER_STEP 22
#define STEPPER_DIR 23
#define STEPPER_EN 26

#define RELE_CHANNEL1 21             //используется для пускателя, который включает нагреватель
#define RELE_CHANNEL2 19             //в режиме "Пиво" используется для включения мешалки
#define RELE_CHANNEL3 18             //используется для клапана, открывающего/закрывающего воду охлаждения
#define RELE_CHANNEL4 5              //если не используется регулятор с управлением, выход используется для управления разгоном

#define ONE_WIRE_BUS 27

#define SERVO_PIN 13

#define BTN_PIN 34

#define LUA_PIN 12

#undef USE_ALARM_BTN

#define WATERSENSOR_PIN 14

#define WHEAD_LEVEL_SENSOR_PIN 15

#define LCD_SDA 33
#define LCD_SCL 32

#define RXD2 25
#define TXD2 4

#define WATER_PUMP_PIN 2
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

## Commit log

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2023-01-11 bugfix & new libraries
    [WebServer.ino, lua.h, sensorinit.h]
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2023-03-01 optimize & bug fix
    [WebServer.ino]
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2023-11-18 Lua pump bugfix
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2023-11-18 3D & default value in program for beer
    [ВОРОНКА САМОВАР_NEW.stl, коробка для шаговика и д.протечки.stl]
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2023-11-24 remove library & correct comments
    [Menu.ino]
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2023-12-02 update pro_mini_ntc
    [case_dw.STL, case_dw_support.STL, case_up.STL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]
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2023-12-28 fix proxy update & run_lua
    [WebServer.ino]
2024-01-18 pro_mini_ntc update
    [ADS.xlsx]
2024-01-31 3d model & library update
    [horn_996_servo.stl, plate_996_servo.stl]
2024-01-31 Revert "berr.h"
    This reverts commit 8e2a4dce2793c54f125f95923ba9360c8751e88c.
    [beer.h]
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2024-02-16 pro_mini_ntc updatw
    [pressure.xls, Попугай.xlsx]
2024-02-25 add SAM AVR 3D model box
    [SAM AVR BOX.stl, SAM AVR TOP.stl]
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2024-03-23 Схемы и модели
    [Нумерация узла разбора.stl]
2024-05-10 add missing TimeLib library & change in Lua_script folder for Lua button
2024-07-31 STL model
    [koromislo.STL, Зажим.STL, Лоток6.STL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]
2024-10-05 nbk, bugfix & new feature
    [FS.ino, I2CStepper.h, WebServer.ino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]
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2024-11-16 Плата и корпус для Самовара
    [Body.SLDPRT, Body.STL, Body2.STL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]
2024-12-07 add platformio settings
    [partitions.csv]
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2024-12-07 update partition & ESPPing
    [partitions.csv, samovar.csv]
2024-12-07 FS & beer fix
    [samovar.csv]
2024-12-07 webserver & beer fix
    [beer.h]
2024-12-29 Create SAM AVR BOX v18.f3d
    [SAM AVR BOX v18.f3d]
2025-01-04 beer bugfix & distiller add time process
    [beer.h, distiller.h, logic.h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]
2025-01-05 SAM AVR BOX
    [SAM AVR BIG BOX.stl, SAM AVR BIG TOP.stl, SAM AVR v22 stoyki.stl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]
2025-01-18 distiller & interface bugfix
    [WebServer.ino, distiller.h]
2025-02-01 bug & include fix
    [Blynk.ino, FS.ino, Menu.ino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]
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2025-05-04 add buzzer in ChangeProgram
    [beer.h, logic.h]
2025-05-04 pro_mini_ntc 3.10
    [ADS.xlsx, Body.SLDPRT, Body.STL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]
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2025-08-09 add partitions.csv
    [partitions.csv]
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2026-01-29 Добавлена гибкая логика детектора примесей с паузами и возобновлением, обновлены точки вызова
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2026-02-01 Добавлена поддержка детектора на головах с настройкой и стабилизацией пара
    - Добавлена новая настройка `useDetectorOnHeads` в структуру `SetupEEPROM` (Samovar.h) и сохранение/загрузку через NVS (NVS_Manager.ino) для управления работой детектора примесей в фазе голов.
    - В WebServer.ino и data/setup.htm добавлен интерфейс включения детектора на головах — чекбокс в настройках с пояснением, что функция отключена по умолчанию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
2026-02-01 Переработка документации: структура, модули и архитектура
    - Полностью переработана диаграмма архитектуры в `architecture.md`: заменена на более понятную с акцентом на компоненты устройства (датчики, исполнительные устройства, интерфейсы), логику управления 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
    - Удалены устаревшие модульные документы (например, `Samovar_ini.md`, `lua.md`, `logic.md`) и соответствующие HTML-страницы, так как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
2026-02-01 Обновление архитектуры и документации: переработана схема системы, обновлены HTML-страницы и метадан
    - Переработана архитектурная диаграмма в `architecture.md`: заменена устаревшая структура на современную с выделением веб-интерфейса, ESP32, логики управления, датчиков и исполнительных устройств с и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
    - Обновлён контент в `architecture.md`: добавлены чёткие блоки (WebServer, MQTT, Lua, PID), ут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
2026-02-01 Добавлены документация по тестированию и конфигурации, обновлены навигация и структура сайта
    - Добавлен новый раздел "Тестирование" с файлом `testing.md` и соответствующей HTML-страницей, включён в навигацию и индекс документации.
    - Внедрены документация и навигация по конфигурационным файлам: `platformio.ini`, `debug.cfg`, `debug_custom.json` — с отдельной категорией "Конфигурация проекта" в меню и поддержк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
2026-02-01 Обновление временной метки генерации и замена 'data' на '/data' в навигации
    - Обновлена временная метка генерации в `.ai-docs/_index.json` и `ai_docs_site/_index.json` с 18:41:17 на 18:52:39
    - Удалён раздел "Тестирование" из списка перегенерированных разделов в `.ai-docs/changes.md` и `ai_docs_site/changes.html`
    - Во всех HTML-файлах заменён текст ссылки в выпадающем меню с "data" на "/data" для единообразия пути
    - Изменение затронуло 63 файла, включа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
2026-02-15 Refactor Samovar logic and improve safety
    - Removed unused WebSocket event handler from FS.ino.
    - Introduced `copyStringSafe` helper function in Samovar.h for safer string copying to fixed-size buffers, replacing direct `toCharArray` calls in Menu.ino, NVS_Manager.ino, and Samovar.ino.
    - Implemented `parseLongSafe` and `parseFloatSafe` in Samovar.h for robust parsing of string inputs, preventing potential crashes with malformed data.
    - Enhanced OTA progress reporting in Samovar.ino to use a safer calculation and `strcpy`/`strcat` for string formatting.
    - Added JSON generation utility functions (`jsonAddKey`, `jsonPrintEscaped`) in Samovar.ino to support AJAX responses.
    - Refactored `send_aja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
    [FS.ino, Menu.ino, NVS_Manager.ino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]
2026-02-20 Refactor FS.ino, Samovar.ino, WebServer.ino for better logging and config handling
    - FS.ino: Changed `Serial.printf("%s", (const char *)data);` to `Serial.write(data, len);` for correct binary data logging during file uploads and request bodies.
    - Samovar.ino: Removed redundant `if (isnan(SamSetup.DistTimeF))` block, as the value is already initialized.
    - WebServer.ino: Removed duplicate function declaration `String wifiKeyProcessor(const String &var);`.
    - Тесты: не запускались.
    [FS.ino, WebServer.ino]
2026-02-25 Refactor NVS and profile saving logic
    - Refactored NVS storage to use separate namespaces for each mode (e.g., "sam_beer", "sam_dist") instead of a single "sam" namespace. This improves organization and prevents cross-mode data corruption.
    - Introduced `current_profile_namespace()` and `profile_namespace_by_mode()` functions to dynamically determine the correct NVS namespace based on the current `Samovar_CR_Mode`.
    - Implemented `read_last_mode_meta()` and `write_last_mode_meta()` to store and retrieve the last used mode from a dedicated "sam_meta" namespace. This ensures the device boots into the correct mode.
    - Modified `FS.ino` to remove redundant SPIFFS profile saving/loading, relying sol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
    [FS.ino, NVS_Manager.ino, WebServer.ino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]
2026-02-25 Refactor: Remove unused getjson function and update web handlers
    - Удалена функция `getjson()` из `Samovar.ino`, так как она больше не используется.
    - В `WebServer.ino` изменен обработчик `web_command()`: удалена проверка на количество параметров, теперь он корректно обрабатывает запросы с аргументом "start".
    - В HTML файлах (`data/beer.htm`, `data/bk.htm`, `data/index.htm`, `data/nbk.htm`, `data/program.htm`) исправлена опечатка в JavaScript коде: `IIsOffline` заменено на `IsOffline`.
    - В HTML файлах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
    [WebServer.ino, logic.h, nbk.h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]
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2026-04-26 Обновление версии в data/version.txt
    Уменьшена версия с 6.27.2 до 6.27
    Изменён файл 'data/version.txt'
    Тесты: не запускались
2026-04-26 Обновление зависимостей и конфигураций CI, рефакторинг кода
    GitHub Actions: обновлён checkout и actions
    Библиотеки и функции: замена методов на безопасные
    Настройки по умолчанию и конфигурации
    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
2026-04-27 Обновление HTML и CSS с безопасной обработкой строк
    Исправление XSS уязвимости в beer.htm
    Замена & на escapeHtml для безопасности
    Переход на синтаксис && вместо &
    Добавление функции toggleTheme
    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
2026-04-27 Добавление темы и переработка интерфейса насоса
    Добавлена функция applyTheme для управления темами
    Добавлен toggleTheme с сохранением в localStorage
    Инициализация темы при загрузке страницы
    Переработан интерфейс насоса с контейнерами
    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
2026-04-27 Обновление i2cstepper.htm: стили, скрипты, интерфейс
    Добавлены стили для панелей и состояний кнопок
    Обновлены функции обработки состояния и реле
    Переработан интерфейс с классами i2c-panel и i2c-actions
    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
2026-04-28 Оптимизация I2CStepper и NVS_Manager, обновление настроек
    Оптимизация чтения I2C регистров в i2c_stepper_refresh
    Добавлена проверка флагов RELAY в set_mixer_pump_target
    Исправлены значения по умолчанию в load_profile_nvs
    Использование loadBytesOrInvalid для безопасного чтения байт
    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
    [I2CStepper.h, NVS_Manager.ino, WebServer.ino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]
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2026-05-03 Исправлены ошибки в интерфейсе и в скетче
    [NVS_Manager.ino, WebServer.ino]
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2026-06-11 Переведена настройка Wi‑Fi на AsyncWiFiManager
    Добавлен AsyncWiFiManager для портала настройки
    Убран старый NVS-обработчик Wi‑Fi кредов
    Сброс Wi‑Fi теперь через resetSettings()
    Упрощена логика старта AP и подключения
    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
    [Menu.ino, NVS_Manager.ino, WebServer.ino]
2026-06-12 Оптимизация работы с NVS и добавление функции сброса настроек
    Удалена небезопасная функция 'rebuild_full_nvs_partition'
    Ограничен размер бэкапа до 'SAMOVAR_NVS_BACKUP_MAX_ENTRIES'
    Добавлены функции 'print_nvs_stats' и 'set_default_setup_profile'
    Исправлены утечки памяти при ошибках чтения NVS
    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
    [NVS_Manager.ino]
2026-07-03 Масштабный рефакторинг архитектуры, внедрение модулей и тестов
    Добавлены модули 'alarm.h', 'mode_common.h' и реестр режимов
    Удален устаревший компонент 'quality.h' из всей системы
    Разработан комплекс скриптов для автоматического дымового тестирования
    Обновлена техническая документация и сгенерирован сайт базы знаний
    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
    [partitions.csv]
2026-07-03 Удалены файлы документации по аудиту безопасности
    Удален файл 'AUDIT.md' с результатами проверки
    Удален файл 'AUDIT_REMEDIATION_PLAN.md' с планом исправления
    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
2026-07-23 Исправлена логика пауз, кипения BK и чекпоинтов сессии NVS
    Унифицирована обработка пауз в меню и Blynk
    Безусловный вызов check_boiling в BK.h
    Добавлены NVS-чекпоинты активных сессий
    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
    [Blynk.ino, Menu.ino, WebServer.ino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]
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2026-08-22 Исправить выбор реализации регулятора питания и игнорирование кэша Python
    Сохранить исходную вложенность условий выбора KVIC, RMVK и SEM
    Уточнить подключение реализаций регулятора через SAMOVAR_USE_POWER
    Добавить каталоги __pycache__ в .gitignore
    Удалить проверку неиспользуемого исходника RMVK
    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
    [power_regulator.h]
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2026-08-23 Унификация runtime-логики, выбора устройств и smoke-тестов
    Добавлены макросы простых Blynk-обработчиков с защитой повторного входа
    Унифицированы работа датчиков, логирование и выбор релейного устройства
    Исправлены контракты Lua, JSON, программ, снимков состояния и событий
    Добавлены smoke-тесты новых сценариев и проверок
    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
    [Blynk.ino, FS.ino, I2CStepper.h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]
2026-08-23 Усилены надежность прошивки, веб-интерфейса и CI-проверок
    Исправлены состояния режимов, насосов, датчиков, Lua и аварийной логики
    Повышена безопасность SPIFFS, JSON, конфигурации и обработки пользовательского ввода
    Обновлены веб-интерфейс, адаптивная верстка и браузерные проверки
    Добавлены smoke-тесты, проверки cppcheck и контроля ISR в IRAM
    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
    [FS.ino, NVS_Manager.ino, WebServer.ino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]
2026-08-25 Улучшены безопасность, режимы работы и веб-интерфейс самовара
    Исправлены переходы режимов, управление исполнительными устройствами и обработка аварийных состояний
    Повышены надежность I2C, Lua, регуляторов мощности и сохранения конфигурации
    Обновлены веб-интерфейс, стили, документация и сжатые ресурсы
    Расширены smoke- и браузерные тесты для новых сценариев
    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
    [Blynk.ino, FS.ino, I2CStepper.h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]
2026-08-25 Исправить безопасную загрузку SPIFFS и отключение нагрева Сувида
    Фиксировать ошибку создания временного файла при заполненной SPIFFS
    Мигрировать устаревший BKPower ниже рабочего порога
    Заменить переключение нагрева на идемпотентную команду выключения
    Расширить smoke-тесты проверками миграции и команд отключения
    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
2026-09-02 Исправлены режимы управления, расчёты программ и веб-интерфейс Samovar
    Устранены ошибки аварийной остановки, автоподстройки, кипячения и управления насосами
    Исправлены расчёты мощности, времени, напряжения и ограничения параметров программ
    Обновлены веб-интерфейс, рецепты, XML-импорт и адаптивные стили
    Расширены smoke- и браузерные тесты функциональности
    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
    [WebServer.ino, alarm.h, beer.h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]
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2026-09-04 Исправления
    [partitions.csv, samovar.csv]
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2026-09-05 fix: repair configurator and runtime controls
    [logic.h]
2026-09-05 fix: improve configurator and process controls
    [I2CStepper.h, Menu.ino, logic.h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]
2026-09-05 feat: add cheese mode and stabilize configurator builds
    [NVS_Manager.ino, WebServer.ino, cheese.h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]
2026-09-05 fix: refine cheese mode and reject UNC builds
    [Menu.ino, WebServer.ino, cheese.h]
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2026-09-05 fix: initialize serial control lines like Arduino
2026-09-05 fix: repair CI checks and serial connection
    [impurity_detector.h]
2026-09-05 fix: update device visibility and serial IP flow
2026-09-06 fix: показывать точные причины ошибок операций
    [mode_switch.h, operation_store.h]
2026-09-06 fix: уточнить причину остановки приводов
    [mode_switch.h, operation_store.h]
2026-09-06 fix: reset stepper state on process stop
    [sensorinit.h]
2026-09-06 fix: clear retained stepper target
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2026-09-06 fix: track Blynk program changes by content
    [Blynk.ino]
2026-09-06 fix: resync Blynk widget values
    [Blynk.ino]
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2026-09-07 feat: complete web UI redesign
    [power_regulator.h]
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2026-09-08 fix: stabilize WiFi and notification handling
    [Blynk.ino, Menu.ino]
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2026-09-08 fix: improve WiFi diagnostics and Lua limits
    [web_server.ino, wifi_utils.ino]
2026-09-08 fix: strengthen Blynk and WiFi recovery
    [Blynk.ino]
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2026-09-09 Увеличены разделы приложений и обновлена проверка SPIFFS
    Размер app0 и app1 увеличен до 0x180000
    Раздел SPIFFS перенесён и уменьшен до 0xE0000
    Обновлено ожидаемое свободное место в smoke-тесте
    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
    [partitions.csv, samovar.csv]
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2026-09-11 Добавлена диагностика core dump и защищена очистка ошибок AsyncTCP
    В отчёты о сбоях добавлены сведения о сохранённом core dump
    Добавлено уведомление об аварийной перезагрузке устройства
    События ошибок AsyncTCP резервируются заранее без выделения памяти
    Исправлено удаление клиентов при ошибке принятия соединения
    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
    [crash_handler.ino]
2026-09-11 Учитывать выключение нагрева в снимках и корректно обрабатывать brownout
    Добавлена подпись состояния PowerOn для обновления снимка при выключении
    Открыта функция добавления core dump для smoke-тестов
    Brownout исключён из аварийных перезагрузок
    Расширены smoke-тесты снимков и обработки причин сброса
    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
    [FS.ino, crash_handler.ino]
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2026-09-17 Исправлено время брожения и улучшена валидация программ
    Добавлен отсчёт времени и завершение этапов брожения с учётом переполнения millis()
    Синхронизированы правила проверки строк программ между прошивкой и интерфейсом
    Добавлены подробные сообщения об ошибках валидации программ
    Обновлены браузерные и дымовые тесты сценариев этапов
    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
    [beer.h, logic.h]
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2026-09-18 Исправлено отложенное включение режима сна во время запуска нагрева
    Команда сна теперь сохраняется как нулевая уставка после запуска.
    Предотвращено включение полной мощности первой командой 'C' или 'W'.
    Добавлен сценарий проверки сна во время запуска нагрева.
    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
    [power_regulator.h]
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2026-09-19 Исправлена нумерация команд и запуск мешалки через конфигурацию
    Добавлена монотонная нумерация отправленных команд для предотвращения дубликатов.
    Команды теперь ожидают завершения операции вместо принятия статуса PENDING.
    Запуск мешалки использует обороты, направление и START_CONFIGURED.
    Расширены smoke-тесты для потерянных подтверждений и отложенных результатов.
    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
    [I2CStepper.h]
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2026-09-20 Добавлена настройка плавного разгона и исправлено переполнение stopStep
    Добавлен флажок плавного разгона и торможения в настройках Nano
    Сохранение изменяет только бит плавного запуска в optionFlags
    Исправлено переполнение stopStep на больших скоростях
    Расширена браузерная проверка сохранения и наследования optionFlags
    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
2026-09-21 Исправлено управление реле насоса при паузе мешалки
    Реле выключается только если его включила программа
    Сохранено ручное состояние реле для строки только с мешалкой
    Добавлены проверки повторного выключения и смены строки
    Добавлены мутационные тесты владения реле
    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
    [beer.h]
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2026-09-21 Интеграция I2C-насоса и исправление логики мешалки
    Добавлена проверка доступности I2C-насоса и безопасный откат запуска
    Уточнены скорость, направление и состояние устройств мешалки
    Обновлены интерфейсы, сжатые ресурсы и сценарии дымового тестирования
    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
    [beer.h, cheese.h, sensorinit.h]
2026-09-21 Исправлена сборка без Blynk и добавлен smoke-тест сессии
    Ограничены Blynk-зависимые функции условной компиляцией
    Добавлена обработка sessionDescription без Blynk
    Добавлен optional smoke-тест tools/smoke_session_blynk_optional.py
    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
2026-09-24 Исправить анимацию отбора голов при использовании второго насоса
    Учитывать второй насос ЦП при определении активного тракта отбора
    Разделить анимацию локального насоса и насоса отбора голов
    Добавить браузерный тест сценариев ректификации и переключения режимов
    Обновить версии ресурсов до 7.00.56
    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
2026-09-24 Исправлена работа ESP32-насоса без I2CStepper
    Разрешена валидация ESP32-насоса без I2C-реле
    Скорректировано управление мешалкой и насосом без I2CStepper
    Обновлены интерфейс насоса и версия до 7.00.59
    Расширены проверки валидации, гонок насоса и браузерного интерфейса
    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
    [beer.h]
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2026-10-06 Исправить паузу отбора, расчёт времени и управление вторым I2C-насосом
    Нулевое значение Blynk V17 переводит отбор в возобновляемую ручную паузу
    Исправлен расчёт времени ректификационных строк с тайм-аутами в секундах
    Добавлено управление скоростью второго I2C-насоса на головах
    Обновлены веб-ресурсы, локализации и сценарии дымового тестирования
    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
    [Blynk.ino, lang_de.h, lang_en.h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]
2026-10-08 Исправить сериализацию программ и мобильную компоновку схемы
    Перейти от childNodes к выборке элементов полей программы
    Разнести приёмные ёмкости на схеме дистиллятора
    Обновить сгенерированные HTML-файлы для всех локалей
    Расширить браузерные проверки мобильной и десктопной разметки
    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
2026-10-11 Исправлена стартовая проверка температуры DS18B20
    Первое измерение теперь ожидается синхронно перед проверкой охлаждения
    Исключено ложное срабатывание на стартовом значении 85°C
    Добавлен сценарий smoke-теста холодного запуска
    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
2026-10-23 Обновление данных до 7.01.1 и исправление объявления функции
    Версия данных поднята с 7.01 до 7.01.1
    Пересобраны все HTML-архивы data и data_i18n
    В Samovar.ino добавлен прототип build_current_log_base_line()
    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
